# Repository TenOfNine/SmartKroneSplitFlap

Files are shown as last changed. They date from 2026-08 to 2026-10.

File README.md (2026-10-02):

<p align="center">Logo: KRONE REW als Fallblatt-Modulreihe</p>

# KRONE REW Fallblattanzeige — Ersatzsteuerung



Eigenbau-Steuerung für eine mechanische Fallblattanzeige der KRONE AG aus dem Jahr 1990. Die Original-Elektronik (Anzeigersteuerung und Palettensteuerungen PST mit HMCS44C) wird ersetzt. Mechanik und Anzeigenplatinen bleiben unverändert.

## Aufbau

```
ESP32-C3 (Master, WLAN/REST/MQTT)
  └─ RS-485 half duplex + CHAIN
       ├─ Daughter Card 1 (ATtiny1616) ── Anzeigenmodul 1
       ├─ Daughter Card 2 ────────────── Anzeigenmodul 2
       └─ …                                        bis 10
```

Jedes Anzeigenmodul erhält eine eigene kleine Steuerplatine, die die Hall-Impulse zählt, den Triac ansteuert und die aktuelle Blattposition kennt. Die Adressvergabe erfolgt automatisch entlang einer CHAIN-Leitung, sodass die Adresse der physischen Position entspricht und ein Kartentausch keine Einstellung erfordert.

## Eckdaten

| Größe | Wert |
|---|---|
| Anzeigenmodule | 10, Palettenmodulreihe A, Modulgröße 1 |
| Blätter je Modul | 40 |
| Zeichensatz | Leerbild, 0–9, A–Z, `-`, `.` |
| Zeit je Blatt | 60 ms, volle Umdrehung 2,40 s |
| Motor | Berger RSM 42/12, 42 V~, 250 U/min |
| Triac | Teccor L201E3, sensitives Gate |
| Modul-CPU | ATtiny1616 |
| Bus | RS-485, 115200 Bd, TP8485E |
| Master | ESP32-C3 Super Mini auf Trägerboard |

## Verzeichnisse

| Pfad | Inhalt |
|---|---|
| `docs/` | Spezifikation, Schaltpläne, Backlog, Toolchain, Symbolprüfungen, Prüfpunkte, Messprotokolle |
| `hardware/daughtercard/` | KiCad-Projekt der Modulsteuerung (geroutet, Fertigungspaket) |
| `hardware/master/` | KiCad-Projekt der Zentralsteuerung (geroutet, Fertigungspaket) |
| `firmware/module/` | ATtiny1616, PlatformIO |
| `firmware/master/` | ESP32-C3, PlatformIO (inkl. Web-UI, `prebuilt/` Flash-Image) |
| `tools/` | Setup, Schaltplan-/PCB-Generatoren, Router-Anbindung, Bus-Testwerkzeug |
| `reference/` | **Nicht versioniert.** Ablage für die Original-Herstellerunterlagen. |

## Stand

| Bereich | Stand |
|---|---|
| Spezifikation, Schaltplan (Netzliste) | vollständig, `docs/` |
| Schaltplan `.kicad_sch` + Footprints + PCB-Netzliste | generiert, ERC 0/0 (Daughter Card + Master) |
| PCB-Layout `.kicad_pcb` | geroutet, DRC 0 Fehler; Daughter Card bei JLCPCB bestellt, Master als Planungsstand |
| Modul-Firmware (ATtiny1616) | fertig, `firmware/module/` |
| Master-Firmware (ESP32-C3 Super Mini) | fertig, `firmware/master/` — Web-Flasher siehe unten |
| Bus-Werkzeug | `tools/busctl.py` |
| CI | `.github/workflows/ci.yml` |
| Offene Messungen O-2, O-5, O-6 | parametrisiert, blockieren die Fertigung nicht |

Der Projektstand für den Einstieg in eine neue Arbeitssitzung steht in
`docs/projektstand.md`.

## Einstieg

```bash
bash tools/setup.sh                              # Toolchain, siehe docs/toolchain.md
source .venv/bin/activate

pio test -e native -d firmware/module            # 62 Tests
pio test -e native -d firmware/master            # 40 Tests
python tools/test_busctl.py                      # 13 Tests
python tools/gen_daughtercard_sch.py --erc --pdf --png
```

## Firmware flashen

**Master (ESP32-C3 Super Mini).** Am einfachsten über den Browser-Flasher:
**<https://tenofnine.github.io/SmartKroneSplitFlap/>**

Nötig: Chrome oder Edge auf dem Desktop, ein USB-C-Kabel **mit Datenadern** an
die Buchse des Moduls. „Modul verbinden & flashen" drücken — der C3 geht selbst
in den Download-Modus, kein BOOT-Taster. Nach dem Flashen öffnet die Karte den
Access-Point `krone_anzeige` für die WLAN-Zugangsdaten. Das fertige Image liegt
committet unter `firmware/master/prebuilt/`; neu bauen mit
`python tools/build_master_firmware.py` oder direkt
`pio run -e esp32c3 -t upload -d firmware/master`.

Die Web-Oberfläche vorab ansehen — dieselbe Seite mit Beispieldaten und
simuliertem Bus, ohne Gerät:
**<https://tenofnine.github.io/SmartKroneSplitFlap/demo/>**
(erzeugt aus `firmware/master/src/main.cpp` per `python tools/build_webui_demo.py`).

Spätere Updates laufen über die Web-UI (*Einstellungen › Firmware aktualisieren*):
den **signierten Container** `firmware/master/prebuilt/krone-master-esp32c3.kota`
hochladen. Das Modul verlangt eine gültige ECDSA-Signatur des Projektschlüssels —
Einrichtung siehe [`docs/firmware-signing.md`](docs/firmware-signing.md). Der
Zugriff auf Web-UI/REST ist ab Werk auf private Netze beschränkt und lässt sich
mit einem Passwort schützen (*Einstellungen › Zugriffsschutz*).

**Daughter Card (ATtiny1616).** Über die UPDI-Stiftleiste J6 mit einem
USB-Seriell-Adapter (FTDI/CP2102/CH340, **auf 5 V**) und einem 4,7-kΩ-Widerstand
zwischen TXD und RXD:

```
  USB-Seriell-Adapter                       Daughter Card J6 (1×3)
  ┌───────────────┐
  │           GND ●──────────────────────────────● 1  GND
  │           TXD ●────[ 4,7 kΩ ]───┬────────────● 2  UPDI   (→ ATtiny PA0)
  │           RXD ●─────────────────┘
  │        5V/VCC ●──────────────────────────────● 3  +5V
  └───────────────┘        └─ nur wenn die Karte sonst keine 5 V hat
```

An UPDI kein Kondensator (Schaltplan 4.4). Dann:

- **Browser:** <https://tenofnine.github.io/SmartKroneSplitFlap/>,
  Tab *Daughter Card* — Werksflash (Bootloader + App + `BOOTEND`-Fuse).
  **Am Gerät verifiziert** (10.09.2026): Chip-Erase, Geräte-ID-Prüfung, Fuse-
  und Seitenschreiben sowie die Bootloader→App-Übergabe laufen auf echter
  Hardware durch.
- **Sicher:** `pio run -e attiny1616 -t upload -d firmware/module` (Protokoll
  `serialupdi`, Port ggf. per `--upload-port`).

Das committete Image liegt unter `firmware/module/prebuilt/`; neu bauen mit
`python tools/build_module_firmware.py`.

## Ausblick

**Modul-Firmware über den Bus verteilen** — die Master-Steuerung flasht die
Daughter Cards aus ihrer Web-UI, ohne PC und Adapter.

- **Residenter Bootloader (umgesetzt, experimentell).** `firmware/bootloader/`
  liegt im per Fuse `BOOTEND = 0x0C` abgetrennten Boot-Bereich (App ab 0x0C00,
  env `attiny1616_boot`). Bei jedem Reset läuft er zuerst, startet die App oder
  empfängt eine neue über den Bus (`ENTER_BOOTLOADER` → `FW_BEGIN`/`_DATA`/`_END`).
  Einzeln adressierbar, ausfallsicher (abgebrochene Updates sind wiederholbar,
  der Bootloader bleibt intakt). Der Master trägt die signierte Modul-Firmware
  eingebettet und verteilt sie aus *Einstellungen › Modul-Firmware*
  („Alle aktualisieren"). Erstflash von Bootloader + App + Fuse über den
  Browser-Werksflasher (Tab „Daughter Card") oder UPDI — **das Werksflashen
  selbst und die Bootloader→App-Übergabe sind am Gerät verifiziert**
  (10.09.2026). `BOOTEND` sperrt den Baustein nicht. Die **Verteilung über den
  Bus** (Master erkennt/aktualisiert die Modul-Firmware) ist noch nicht
  getestet — Design und Bench-Test-Checkliste in
  [`docs/module-bootloader.md`](docs/module-bootloader.md); bis dahin
  `pio run -e attiny1616 -t upload` (ohne Bootloader) als abgesicherter Weg – ab Firmware 1.16 (setzt bei `BOOTEND≠0` selbst IVSEL); ältere Plain-Apps auf einer werksgeflashten Karte (BOOTEND=0x0C) legen die Interrupts lahm – Issue #19.
- **UPDI-Ader im Flachbandkabel (verworfener Bastelweg).** Ader 9 des Busbands
  ist frei; eine Drahtbrücke je Karte von `J6.2` auf `J2.9` brächte UPDI auf den
  Bus, aber allen zehn Karten gemeinsam (kein Einzeladressieren). Der
  Bootloader-Weg ist die bessere Lösung.

## Hinweis zu den Originalunterlagen

Die technische Dokumentation der KRONE AG ist urheberrechtlich geschützt und trägt einen ausdrücklichen Vervielfältigungsvorbehalt. Sie gehört nach `reference/` und ist über `.gitignore` von der Versionierung ausgenommen. In den Dokumenten dieses Repositories wird auf Zeichnungsnummern verwiesen, nicht aus den Unterlagen zitiert.

Alle eigenen Inhalte — Spezifikation, Schaltplan, Firmware, Messprotokolle, Fotos der eigenen Hardware — sind davon nicht betroffen.

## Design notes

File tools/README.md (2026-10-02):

# tools

Python-Skripte laufen in der venv (`source .venv/bin/activate`) — **außer** die
mit `pcbnew`, die brauchen das System-Python (`/usr/bin/python3`).

## Einrichtung

| Werkzeug | Zweck |
|---|---|
| `setup.sh` | Toolchain der Entwicklungs-VM (KiCad 9, venv, PlatformIO, Bibliothekstabellen). `--kicad-config` nur die KiCad-Config. Siehe `docs/toolchain.md`. |
| `setup_freerouting.sh` | FreeRouting 2.3.0 + Temurin-JRE 25 nach `tools/vendor/` laden (gitignored). |

## Daughter Card (KiCad)

| Werkzeug | Zweck |
|---|---|
| `build_krone_symbols.py` | Symbolbibliothek `hardware/daughtercard/symbols/krone.kicad_sym`. `--check` für die CI. |
| `gen_daughtercard_sch.py` | Schaltplan + PDF + PNG + PCB-Netzliste aus `docs/schaltplan-daughtercard.md` Kap. 6. `--check-only`, `--erc`, `--pdf`, `--png`, `--netlist`. |
| `gen_daughtercard_pcb.py` | Erstplatzierung der `.kicad_pcb` (**System-Python**, `pcbnew`). `--png`, `--drc`, `--jlc`, `--render` (3D → `docs/render-daughtercard-*.png`, baut nicht neu). Verweigert Neuaufbau nach dem Routing nicht — dann UUID-Remapping statt Neu-Erzeugen. |
| `route_daughtercard.py` | FreeRouting + `finish_routes.py` + Masseflächen (**System-Python**). `--dry-run`, `--no-zones`. |
| `finish_routes.py` | A*-Rastersuch-Router für die 1–2 Verbindungen, die FreeRouting offen lässt. Von `route_*` importiert, braucht `python3-numpy`. |
| `add_silk_marks.py` | Maker-Kennzeichnung + schwarz/weiß-Lagenaufbau (**System-Python**). `--board <pfad>` auch für den Master. |
| `gen_manufacturing.py` | Fertigungspaket → `hardware/daughtercard/manufacturing/` (committet). `--no-gerber`. |

## Master / Zentralsteuerung (KiCad)

| Werkzeug | Zweck |
|---|---|
| `build_krone_master_symbols.py` | `hardware/master/symbols/krone_master.kicad_sym` (inkl. handgebautem `ESP32-C3-SuperMini`-Symbol). `--check` für die CI. |
| `gen_master_sch.py` | Schaltplan aus `docs/schaltplan-master.md` Kap. 6. Flags wie beim Daughter-Card-Pendant. |
| `gen_master_pcb.py` | Erstplatzierung `hardware/master/master.kicad_pcb` (**System-Python**). `PLACEMENT`-Dict (opt. 4. Element `"B"` = Rückseite). `--png`, `--drc`, `--jlc`, `--render` (3D aus der Datei), `--preview` (2D `docs/pcb-master.png` aus der Datei), `--force`. |
| `route_master.py` | wie `route_daughtercard.py` für die Master-Platine, ruft `add_silk_marks.py` selbst auf. FreeRouting mit `-Dfreerouting.gui.enabled=false` + Popen-Watchdog (JVM hängt sonst nach dem Routing), `--passes`-Default 6, bis zu 3 Anläufe. |
| `patch_master_pcb.py` | **inkrementell**: setzt die in `gen_master_pcb.PLACEMENT` neuen Refs in die geroutete Platine (`git show <base>`) ein, kappt kurzschließende Bahnen, schließt Lücken mit `finish_routes.py` (bis 4 Runden), setzt Referenztexte aus `REF_POS_MM`, baut Masseflächen neu, End-DRC. Für kleine Revisionen ohne Vollneuroute (Rev. 0.2: Q1/R8/D2). **System-Python.** |
| `gen_master_manufacturing.py` | Fertigungspaket → `hardware/master/manufacturing/`. |

## Firmware

| Werkzeug | Zweck |
|---|---|
| `check_flash.py` | Flash-Verbrauch einer ELF gegen eine Obergrenze prüfen (CI, ATtiny < 8 KB). |
| `check_webui.mjs` | prüft `INDEX_HTML` in `firmware/master/src/main.cpp`: JS-Syntax jedes Inline-`<script>` + optionaler jsdom-Smoke (Seite laden, `/api/*` mocken, Navigation testen). Prüft zusätzlich das Demo-Bundle, falls gebaut. `node tools/check_webui.mjs` (jsdom optional: `npm i jsdom@24`). |
| `build_webui_demo.py` | statische Demo der Master-Web-UI für die GitHub Page: schneidet `INDEX_HTML` aus `main.cpp`, setzt den Demo-Shim (`webui_demo_shim.html`, `window.fetch`-Überlagerung für `/api/*` mit Beispieldaten) davor → `firmware/master/prebuilt/demo/index.html` (gitignored, in CI/Pages erzeugt). `--check` = nur prüfen. |
| `build_master_firmware.py` | `pio run -e esp32c3` + `esptool merge_bin` → `firmware/master/prebuilt/` (`factory.bin` für USB + signierte `.kota` fürs Browser-OTA + Manifest). |
| `make_release.py` | Release-Paket: prüft Versionsgleichstand (Master, Modul, `module_fw.h`), CHANGELOG-Zeile und committete Prebuilts, legt das Tag `vMAJOR.MINOR` an. Der Tag-Push erzeugt per CI das GitHub-Release; Pages spiegelt es für die Versionsauswahl im Webflasher. |
| `build_module_firmware.py` | baut `attiny1616` (App @ 0x0000), `attiny1616_boot` (App @ 0x0C00) und den Bootloader → `firmware/module/prebuilt/` (drei Hex + signierte `.mota` für die Bus-Verteilung). |
| `ota_keys.py` | OTA-Signaturschlüssel: `init` (ECDSA-P-256-Paar + `lib/otaverify/ota_pubkey.h`), `pubkey`, `sign IN.bin OUT.kota`, `verify`. Privater Schlüssel nie im Repo. Siehe `docs/firmware-signing.md`. |

## Bus

| Werkzeug | Zweck |
|---|---|
| `busctl.py` | Kommandozeilenwerkzeug für den KRONE-REW-Bus (T9). |
| `test_busctl.py` | stdlib-`unittest` für `busctl.py` (13 Tests). |

## busctl.py

Für die stufenweise Inbetriebnahme nach `docs/spezifikation.md` Kapitel 10.
Enthält seit T17 auch die Bootloader-Kommandos (5.7, `GET_VERSION`/
`ENTER_BOOTLOADER`/`FW_BEGIN`/`FW_DATA`/`FW_END`, 0x54–0x58) — damit lassen
sich die Bench-Punkte 3+4 aus `docs/module-bootloader.md` (und mit `fwbegin`/
`fwdata`/`fwend` von Hand auch 5–8) direkt am PC gegen echte Karten prüfen,
ganz ohne Master-Hardware.

```bash
source ../.venv/bin/activate

# gegen echte Hardware (USB-RS485-Adapter):
python busctl.py --port /dev/ttyUSB0 enum
python busctl.py --port /dev/ttyUSB0 status 3
python busctl.py --port /dev/ttyUSB0 show 13 3 40 1 1     # SET_ALL + GO
python busctl.py --port /dev/ttyUSB0 sniff 10             # Rohrahmen mitschneiden
python busctl.py --port /dev/ttyUSB0 version 3             # GET_VERSION (App + Bootloader)
python busctl.py --port /dev/ttyUSB0 enterboot 3           # ENTER_BOOTLOADER

# Adapter ohne automatische Sende-/Empfangsumschaltung (z. B. ein MAX485-
# Modul mit getrennten DE/RE-Pins): DE und RE brücken, an RTS ODER DTR des
# USB-Serial-Adapters anschließen (je nachdem, was dort herausgeführt ist),
# dann --rts-rs485 bzw. --dtr-rs485:
python busctl.py --port /dev/ttyUSB0 --rts-rs485 enum
python busctl.py --port /dev/ttyUSB0 --dtr-rs485 enum

# ohne Hardware:
python busctl.py selftest              # Rahmen-/CRC-Logik
python busctl.py --sim 3 enum          # 3 simulierte Module
python busctl.py --sim 3 -v status 2   # -v zeigt die Rohrahmen
python test_busctl.py                  # Tests
```

Unterkommandos: `enum`, `status`, `uid`, `ping`, `set`, `show`, `home`, `stop`,
`config`, `sniff`, `selftest`.

Die Rahmen-/CRC-Logik ist ein eigenständiger Python-Nachbau von
`firmware/module/lib/protocol`. `selftest` prüft sie gegen dieselben Goldwerte
wie die C-Tests (CRC von `"123456789"` = `0x4B37`, Rahmenkopf `AA 55 05 01 03 28`).

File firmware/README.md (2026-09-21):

# firmware/

Master- und Modul-Firmware der KRONE-REW-Ersatzsteuerung. Details je Ziel:
[`master/README.md`](master/README.md) (ESP32-C3), [`module/README.md`](module/README.md)
(ATtiny1616). Gemeinsame Versionsnummer + Historie: [`CHANGELOG.md`](CHANGELOG.md).

## Speicherprofil

Firmware-Speicherprofil

Aufschlüsselung des Flash-Speicherverbrauchs nach Bereich (Web-UI/eigener Code,
WLAN-Stack, Krypto/TLS, Motor-/Enumerations-Logik, ...), gemessen am jeweils
gelinkten Firmware-Abbild (`firmware.map` bzw. `avr-nm --size-sort` gegen die
ELF-Datei). Die Modul-Zahlen stammen aus einem einmaligen Analyse-Build ohne
`-flto` (damit Funktionsgrenzen als eigene Symbole sichtbar bleiben) -- das
ausgelieferte Abbild wird weiterhin mit `-flto` gebaut und ist ein paar Bytes
kleiner.

Neu erzeugen nach jeder Firmware-Änderung:

```bash
python tools/gen_firmware_memory_chart.py
```

(Siehe CLAUDE.md Arbeitsweise -- gehört zu den nach jeder Firmware-Änderung neu
zu erzeugenden Dateien, wie `prebuilt/`.)

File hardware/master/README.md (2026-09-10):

# hardware/master

KiCad-Projekt der Zentralsteuerung (RS-485-Master, eine je Anlage).
**Stand:** Rev. 0.2 **fertig** — geroutet + GUI-Feinlayout (2 Lagen, ERC 0/0,
DRC 0/0/0), Symbolprüfung freigegeben, Fertigungspaket committet unter
`manufacturing/`. **Bereit zur Bestellung.** Rev. 0.2 = Eingangsschutz
(Verpol-P-FET Q1 + R8, RS-485-TVS D2) + Silk (+/- an J1, „ANT"-Text raus,
Referenztexte U2/D2/R4 am Bauteil). Die `master.kicad_pcb` ist der finale
Stand des Betreibers — nicht mehr per Skript regenerieren.

## Schnellcheck

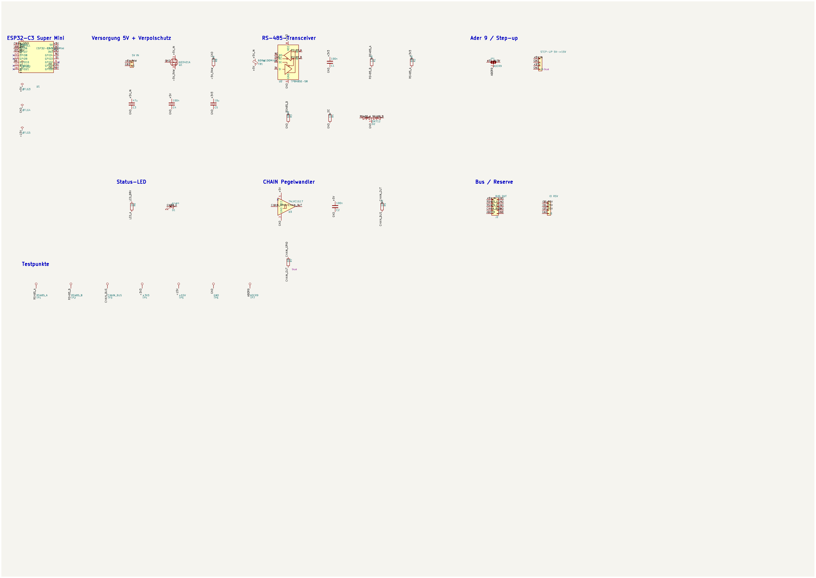
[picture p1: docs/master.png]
Schaltplan-Vorschau


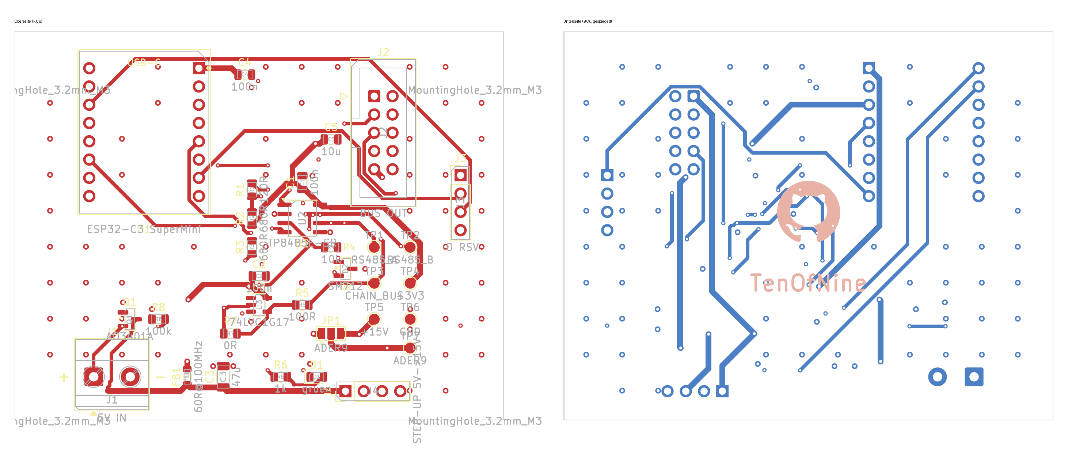
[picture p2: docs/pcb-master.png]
PCB (geroutet, F.Cu + B.Cu)


3D-Vorschau (`tools/gen_master_pcb.py --render`):

| Oberseite | Unterseite |
|---|---|
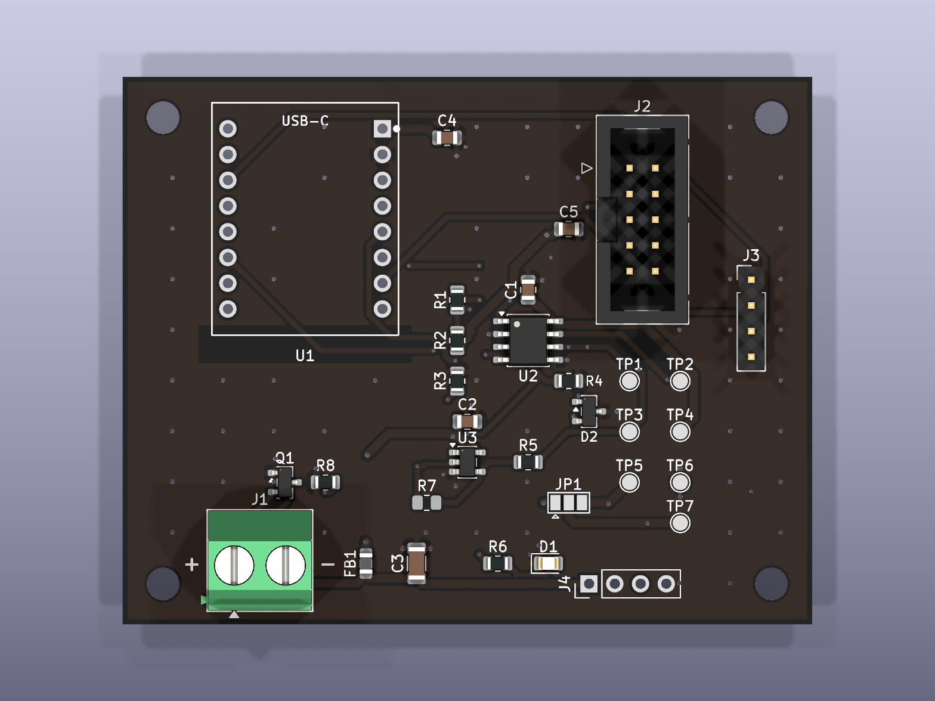
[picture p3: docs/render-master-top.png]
3D oben
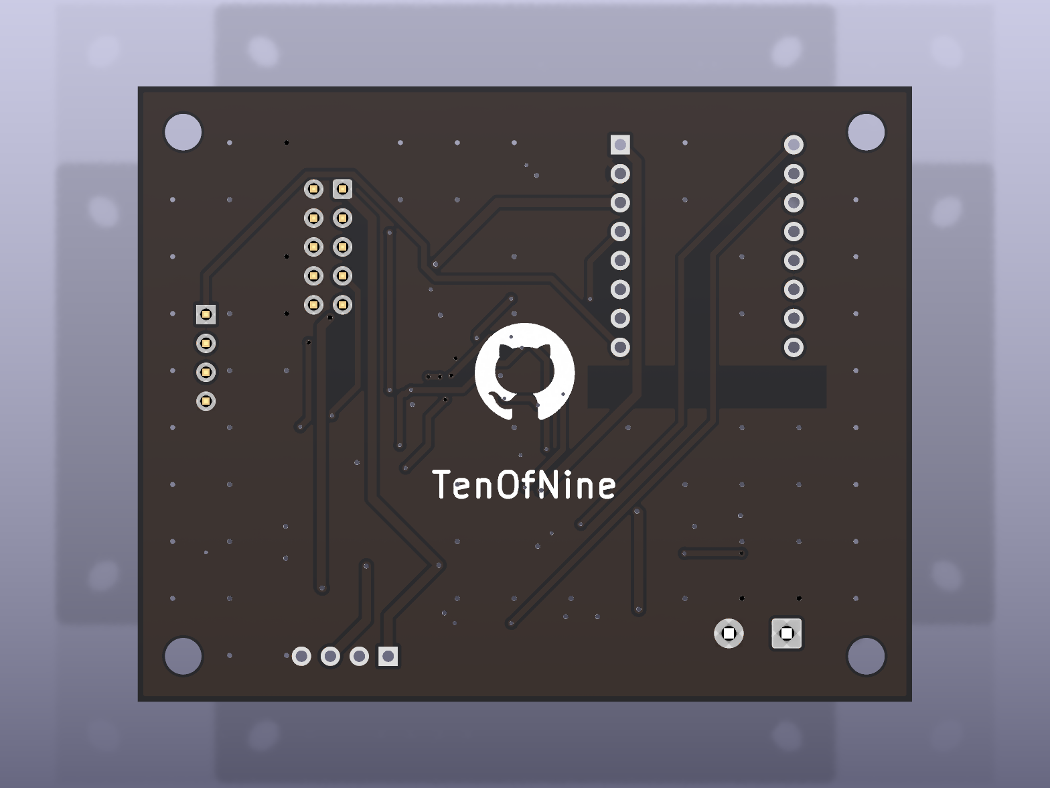
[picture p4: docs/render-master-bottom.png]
3D unten
|  |  |

Vollauflösung Schaltplan: [`docs/master.pdf`](../../docs/master.pdf) ·
ERC: 0 Fehler / 0 Warnungen (`gen_master_sch.py --erc`, in der CI geprüft) ·
DRC: 0 Fehler / 0 Warnungen / 0 unverdrahtet (Rev. 0.2). Feinlayout im GUI
(Bahnführung, Bestückungsdruck) ist Sache des Betreibers.

## Dateien

| Datei | Herkunft |
|---|---|
| `symbols/krone_master.kicad_sym` | **generiert** von `tools/build_krone_master_symbols.py`. Die 13 im Schaltplan verwendeten Symbole: Standardteile abgeflacht aus der KiCad-9-Bibliothek, `TP8485E-SR` wie bei der Daughter Card zusammengesetzt, `ESP32-C3-SuperMini` (16-Pin-Modul, 2×8) von Hand. Nicht bearbeiten. |
| `sym-lib-table` | projektlokale Bibliothekstabelle, bindet `krone_master` über `${KIPRJMOD}` ein |
| `footprints/logos.pretty/` | GitHub-Marke für die Rückseiten-Silkscreen (projektlokal, wie bei der Daughter Card) |
| `footprints/modules.pretty/` | `ESP32-C3-SuperMini.kicad_mod` — 2×8-THT für Buchsenleisten, Reihenabstand 15,24 mm, Pad 1 = 5V rechts oben, Antennen-Keepout an der Unterkante. Von Hand erstellt (kein Standard-Footprint). |
| `fp-lib-table` | projektlokale Footprint-Tabelle für die beiden `.pretty`-Ordner |
| `master.kicad_sch` | **generiert** von `tools/gen_master_sch.py` aus Netzliste (`docs/schaltplan-master.md` Kap. 6) und Footprint-Tabelle. 32 Bauteile, 20 Netze. |
| `master.kicad_pro` | Projektfile: projektlokale `sym-lib-table` / `fp-lib-table` + Netzklassen (Default, Power, GND — **kein AC**) aus Schaltplan Kap. 8 |
| `master.kicad_pcb` | Rev. 0.1: **Erstplatzierung** `tools/gen_master_pcb.py` + FreeRouting (`route_master.py`). Rev. 0.2 (Q1/R8/D2): **inkrementell** mit `tools/patch_master_pcb.py` in die geroutete Rev-0.1-Platine eingesetzt und mit `finish_routes.py` geschlossen (FreeRouting 2.3.0 hängt hier reproduzierbar). Maker-Mark / schwarz-weiß-Lagenaufbau von `tools/add_silk_marks.py --board …`. DRC 0/0. |
| `manufacturing/` | committetes Fertigungspaket (Gerber, Bohrdatei, Zip, BOM, CPL, README) von `tools/gen_master_manufacturing.py`. |
| `master.net` | **generiert** (`--netlist`), nicht versioniert. PCB-Netzliste. |

## Neu erzeugen

```bash
source .venv/bin/activate
python tools/build_krone_master_symbols.py                          # nur bei Änderung der Symbolauswahl
xvfb-run -a python tools/gen_master_sch.py --erc --pdf --png --netlist
```

**Vorsicht bei der `.kicad_pcb`:** Die Generatoren vergeben bei jedem Lauf neue
UUIDs. Solange die Platine noch nicht platziert/geroutet ist, gilt: `.kicad_sch`
+ `.kicad_pcb` nach einer Netzlistenänderung gemeinsam neu erzeugen und committen.
**Sobald die `.kicad_pcb` geroutet ist** (aktueller Stand), wird sie **nicht**
neu erzeugt — `tools/gen_master_pcb.py` verweigert den Neubau, wenn Bahnen oder
Zonen vorhanden sind (`--force`-Schutz). Eine Netzlistenänderung erfordert
stattdessen ein UUID-Remapping der Footprint-Pfade und danach
`tools/route_master.py`. Details: `docs/layout-master.md`.

| Flag (`gen_master_sch.py`) | Ausgabe |
|---|---|
| `--erc` | `docs/erc-master.rpt` |
| `--pdf` | `docs/master.pdf` |
| `--png` | `docs/master.png` (Vorschau ohne Rahmen, für GitHub) |
| `--netlist` | `master.net` (PCB-Netzliste, nicht versioniert) |

`--check-only` (bzw. `--check` bei `build_krone_master_symbols.py`) prüft ohne zu
schreiben — für die CI (T10). Der Check umfasst: jeder Pin an genau einem Netz
oder NC, jedes Bauteil mit vorhandenem Footprint.

Netznamen tragen im Netlist-Export das KiCad-übliche Wurzelblatt-Präfix (`/+5V`,
`/GND` …), weil die Rails über lokale Labels laufen. Für den PCB-Import ist das
unerheblich.

## Zum Schaltplan

Die Verbindungen werden über **gleichnamige lokale Labels an den Pins** hergestellt,
nicht über gezeichnete Leitungen. Die Bauteile liegen in einem groben Raster, nicht
handverlegt. Das ist bewusst so:

- Die menschenlesbare Darstellung der Schaltung ist `docs/schaltplan-master.md`
  Kapitel 5 (Prinzipschaltbilder) und Kapitel 6 (verbindliche Netzliste).
- Die `.kicad_sch` ist das maschinell erzeugte Abbild von Kapitel 6 für ERC,
  Netzlistenexport und das Layout.

## Layout und Routing

Footprints sind allen 32 Bauteilen zugeordnet (`FOOTPRINTS` in
`tools/gen_master_sch.py`). Die Platine ist geroutet — Erstplatzierung, Zonen,
Netzklassen (alle Bahnen 0,5 mm, Power `+5V(_RAW/_IN)`/`+3V3`/`+15V`/`ADER9`
0,8 mm mit 0,8-mm-Vias), Masseflächen F.Cu + B.Cu mit 5-mm-Stitching und die
offenen Punkte mit Layoutbezug stehen in
[`docs/layout-master.md`](../../docs/layout-master.md).
Die Massefläche ist nur im Antennenbereich unter U1 ausgespart (Footprint-Keepout).
Die JLCPCB-Bestückung beschreibt [`manufacturing/README.md`](manufacturing/README.md):
18 SMD-Teile (0805 / SOIC-8 / SOT-23 / SOT-23-5), alle LCSC-Basic; J1–J4,
U1-Sockel und JP1 von Hand.

## Prüfpunkte

`docs/symbolpruefung-master.md` ist vom Betreiber **freigegeben** (01.09.2026):
74LVC1G17 gegen Nexperia Rev. 16.1 §6.1, ESP32-C3-Modul-Pinbelegung und
Einbaulage aus den Betreiberfotos, TP8485E per Verweis. **Rev. 0.2 nachgetragen,
Freigabe offen:** AO3401A (SOT-23 1=G/2=S/3=D) und SM712 (Pin 3 = GND, gegen
Bourns-CDSOT23-SM712-Datenblatt).

Offen (blockieren die Fertigung nicht bzw. sind vor der Bestellung zu klären):

| Nr | Punkt | Wirkung |
|---|---|---|
| M-2 | Aufwärtswandler-IC + Pinbelegung | Boost-Steckplatz J4 bleibt DNP, bis O-2 gemessen ist |
| M-3 | CHAIN 3,3 V → 5 V | **entschieden:** U3 wird bestückt, R7 (0 Ω) DNP-Reserveplatz |
| M-4 | RS-485-TVS D2 (SM712/PSM712) | Pinbelegung gegen Bourns-Datenblatt geprüft; ProTek-Spot-Check + Freigabe vor Bestellung |
| O-2 | 5 V oder 12–20 V an Anzeige-Pin 9 | ob JP1 auf +15 V steht und der Boost bestückt wird |

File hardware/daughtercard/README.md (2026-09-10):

# hardware/daughtercard

KiCad-Projekt der Modulsteuerung (eine je Anzeigenmodul).
**Stand:** geroutet (2 Lagen, DRC 0 Fehler), Fertigungspaket committet unter
`manufacturing/`, bei JLCPCB in Auftrag.

## Schnellcheck

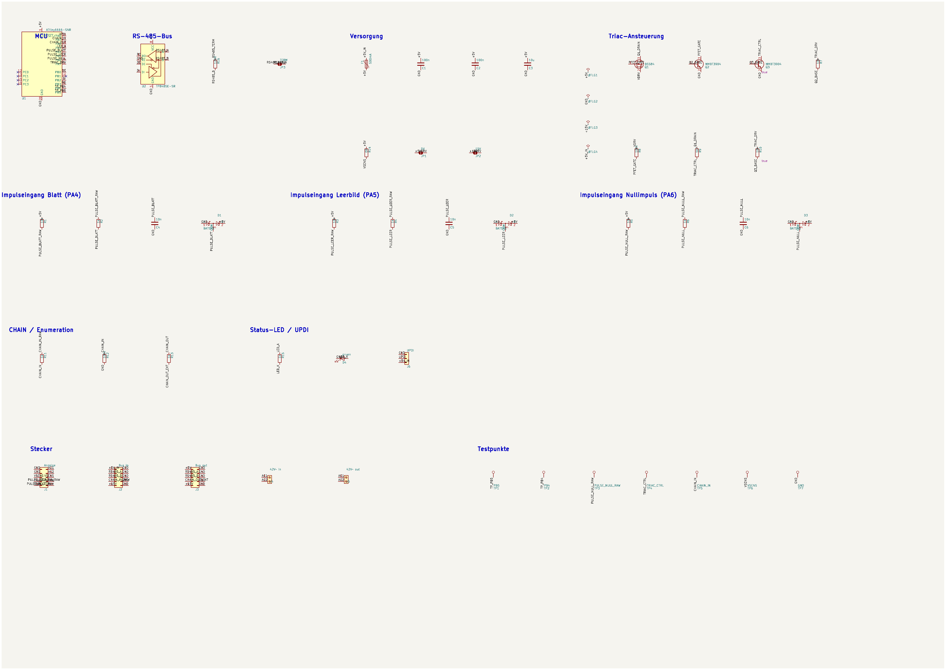
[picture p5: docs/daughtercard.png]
Schaltplan-Vorschau


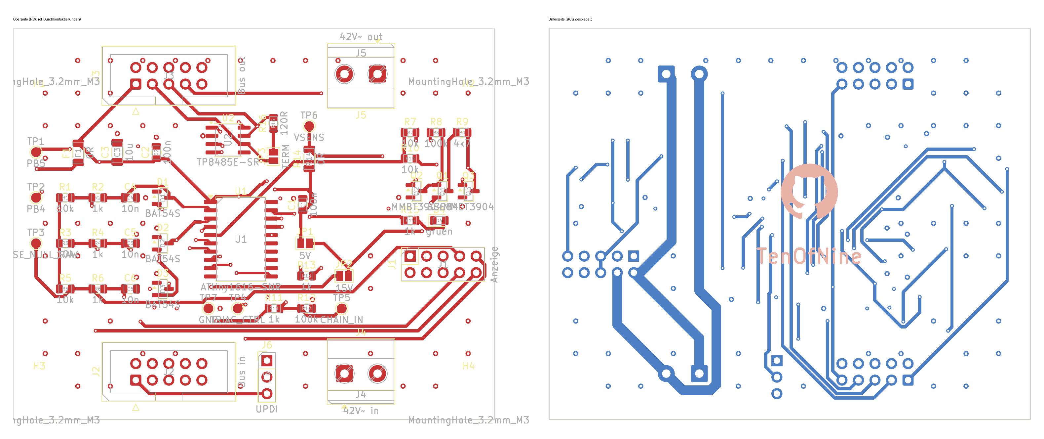
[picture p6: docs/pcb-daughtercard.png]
PCB (geroutet, F.Cu + B.Cu)


3D-Vorschau (`tools/gen_daughtercard_pcb.py --render`):

| Oberseite | Unterseite |
|---|---|
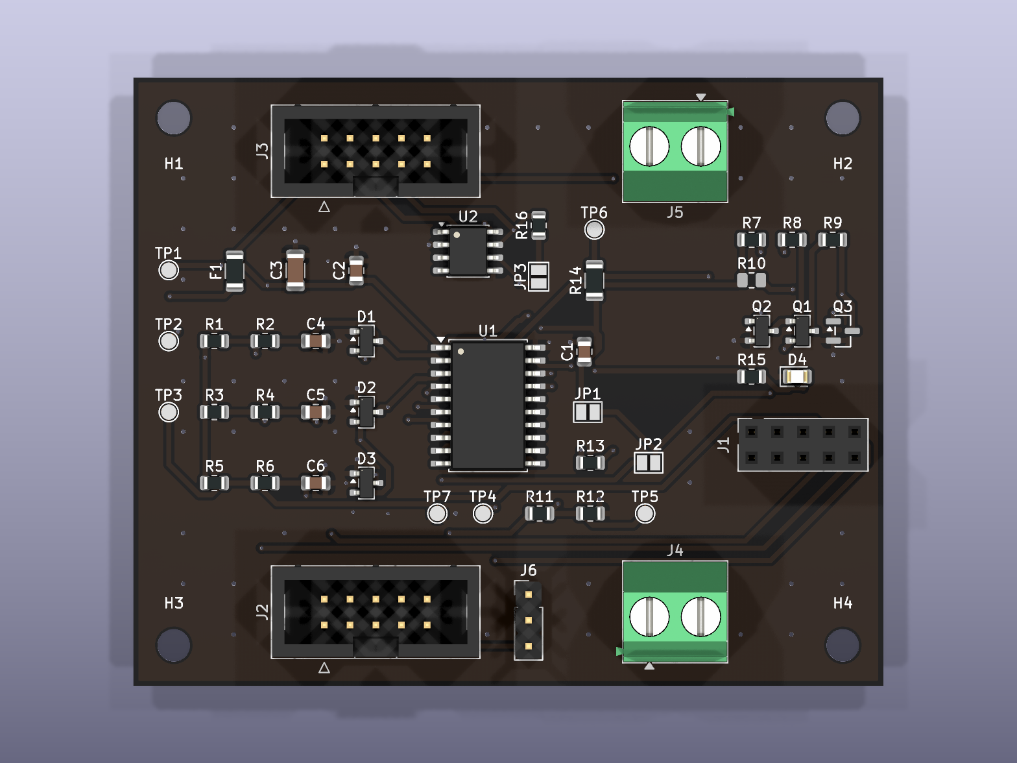
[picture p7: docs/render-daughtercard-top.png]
3D oben
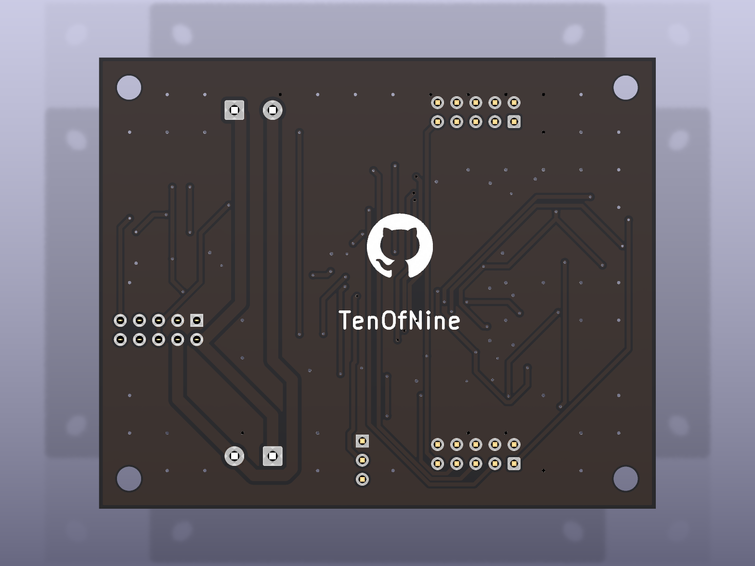
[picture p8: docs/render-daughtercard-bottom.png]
3D unten
|  |  |

Vollauflösung Schaltplan: [`docs/daughtercard.pdf`](../../docs/daughtercard.pdf) ·
ERC: 0 Fehler / 0 Warnungen (`gen_daughtercard_sch.py --erc`, in der CI geprüft)

## Dateien

| Datei | Herkunft |
|---|---|
| `symbols/krone.kicad_sym` | **generiert** von `tools/build_krone_symbols.py` aus der KiCad-9-Bibliothek. Alle 15 im Schaltplan verwendeten Symbole, abgeflacht. Nicht von Hand bearbeiten. |
| `sym-lib-table` | projektlokale Bibliothekstabelle, bindet `krone` über `${KIPRJMOD}` ein |
| `daughtercard.kicad_sch` | **generiert** von `tools/gen_daughtercard_sch.py` aus Netzliste (`docs/schaltplan-daughtercard.md` Kap. 6) und Footprint-Tabelle (T5) |
| `daughtercard.kicad_pro` | Projektfile: projektlokale `sym-lib-table` + Netzklassen (AC, RS485, Power) aus Schaltplan Kap. 8.2 |
| `daughtercard.kicad_pcb` | **Erstplatzierung** von `tools/gen_daughtercard_pcb.py` (System-Python, `pcbnew`), danach vom Betreiber feinjustiert und mit `tools/route_daughtercard.py` (FreeRouting + `finish_routes.py` + Masseflächen) verdrahtet. Maker-Mark / schwarz-weiß-Lagenaufbau von `tools/add_silk_marks.py`. |
| `manufacturing/` | committetes Fertigungspaket (Gerber, Bohrdatei, Zip, BOM, CPL, README) von `tools/gen_manufacturing.py`. |
| `daughtercard.net` | **generiert** (`--netlist`), nicht versioniert. PCB-Netzliste. |

## Neu erzeugen

```bash
source .venv/bin/activate
python tools/build_krone_symbols.py                            # nur bei Änderung der Symbolauswahl
python tools/gen_daughtercard_sch.py --erc --pdf --png --netlist
```

**Vorsicht bei der `.kicad_pcb`:** Die Generatoren vergeben bei jedem Lauf neue
UUIDs. Solange die Platine noch nicht platziert/geroutet ist, gilt: `.kicad_sch`
+ `.kicad_pcb` nach einer Netzlistenänderung gemeinsam neu erzeugen und committen.
**Sobald die `.kicad_pcb` platziert/geroutet ist** (aktueller Stand), wird sie
**nicht** neu erzeugt — eine Netzlistenänderung erfordert stattdessen ein
UUID-Remapping der Footprint-Pfade (siehe Commit „F1 → 0-Ω-Brücke") und danach
`tools/route_daughtercard.py`. Details: `docs/layout-daughtercard.md`.

| Flag | Ausgabe |
|---|---|
| `--erc` | `docs/erc-daughtercard.rpt` |
| `--pdf` | `docs/daughtercard.pdf` |
| `--png` | `docs/daughtercard.png` (Vorschau ohne Rahmen, für GitHub) |
| `--netlist` | `daughtercard.net` (PCB-Netzliste, nicht versioniert) |

`--check-only` (bzw. `--check` bei `build_krone_symbols.py`) prüft ohne zu schreiben —
für die CI (T10). Der Check umfasst: jeder Pin an genau einem Netz oder NC, jedes
Bauteil mit vorhandenem Footprint.

Netznamen tragen im Netlist-Export das KiCad-übliche Wurzelblatt-Präfix (`/+5V`,
`/GND` …), weil die Rails über lokale Labels laufen. Für den PCB-Import ist das
unerheblich; wer es ohne Präfix will, stellt die Rails auf Power-Symbole um.

## Zum Schaltplan

Die Verbindungen werden über **gleichnamige lokale Labels an den Pins** hergestellt,
nicht über gezeichnete Leitungen. Die Bauteile liegen in einem groben Raster, nicht
handverlegt. Das ist bewusst so:

- Die menschenlesbare Darstellung der Schaltung ist `docs/schaltplan-daughtercard.md`
  Kapitel 5 (Prinzipschaltbilder) und Kapitel 6 (verbindliche Netzliste).
- Die `.kicad_sch` ist das maschinell erzeugte Abbild von Kapitel 6 für ERC,
  Netzlistenexport und – nach dem Footprint-Schritt T5 – das Layout.

Eine handverlegte, ablesbare Schaltplanseite kann später folgen; sie ist nicht
Teil von T4.

## Layout (T5) und Routing

Footprints sind allen 48 Bauteilen zugeordnet (`FOOTPRINTS` in
`tools/gen_daughtercard_sch.py`). Die Platine ist geroutet — Zonen, Netzklassen
(alle Bahnen 0,5 mm außer AC 1,5 mm), Masseflächen und die offenen Punkte mit
Layoutbezug stehen in [`docs/layout-daughtercard.md`](../../docs/layout-daughtercard.md),
die JLCPCB-Bestückung in [`docs/jlc-bestueckung.md`](../../docs/jlc-bestueckung.md).

## Prüfpunkte

Die zwei Netzlisten-Entscheidungen aus T4 (P-1 Testpads, P-2 BAT54S) sind vom
Betreiber freigegeben, siehe [`docs/pruefpunkte-t4.md`](../../docs/pruefpunkte-t4.md).

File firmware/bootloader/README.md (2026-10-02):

# firmware/bootloader

Residenter Bootloader der Modulsteuerung (ATtiny1616, bare metal).
Am Gerät verifiziert seit Firmware v1.9 (Werksflash, Bus-Update Ende-zu-Ende,
siehe [`docs/module-bootloader.md`](../../docs/module-bootloader.md)).
Änderungen ab `BL_VERSION` 2 (`src/board.h`) sind bisher nur auf dem Host
getestet; der Bootloader erreicht die Karten nur per UPDI-Werksflash.

```bash
pio run -e bootloader        # ~2,7 KiB, Boot-Sektion 3 KiB (Fuse BOOTEND = 0x0C)
```

Liegt im Flash ab 0x0000, die Anwendung ab 0x0C00 (`firmware/module` env
`attiny1616_boot`). Empfängt die Firmware über USART0/RS-485 mit derselben
Rahmenschicht wie die App (`lib/protocol`), sammelt die Seiten über
`lib/fwupdate` und schreibt sie per `NVMCTRL`.

Alle Entscheidungen (Startfenster, App-Gültigkeit, Annahme von Rahmen,
Wiederaufsetzen) trifft `lib/fwupdate/fwboot` — hardwareunabhängig und mit
`pio test -e native -d firmware/module` (Suite `test_fwupdate`) getestet.
`src/main.c` macht nur Hardware: USART0 gepollt, TCB0 als 1-ms-Zeitbasis,
NVMCTRL, EEPROM. Hardwarenahe Konstanten stehen ausschließlich in
`src/board.h`.

Verhalten (BL_VERSION 2):

- App startbar = erstes App-Wort ≠ `0xFFFF` **und** EEPROM-Byte 8 = `0xA5`
  (Bus-Update fertig) oder `0xFF` (Werksflash).
- Startbare App, kein `ENTER_BOOTLOADER`-Marker → Startfenster 2,5 s (echte
  Zeit über TCB0). `FW_BEGIN` an die eigene Adresse startet ein Update, jeder
  andere Rahmen an sie startet sofort die App, Broadcasts und fremde Adressen
  verlängern oder beenden das Fenster nicht.
- Sonst warten. Nach `FW_BEGIN` (Byte 8 = `0x00`) ist die App bis zum
  erfolgreichen `FW_END` nicht startbar — weder nach Busstille noch nach einem
  Neustart.
- Wiederaufsetzbar: Wiederholung des letzten `FW_DATA` wird bestätigt,
  `FW_BEGIN` startet jederzeit neu, Leerlauf beendet die Übertragung nicht.
- Nur Unicast an die eigene Adresse (ungültige EEPROM-Adresse → 250) mit
  passender Nutzlastlänge; Antwort frühestens 200 µs nach Rahmenende.
- `GET_VERSION`: `[1 · 0xFF · 0xFF · flags · BL_VERSION]`, `APP_VALID` nach
  aktuellem Stand.

Der Bootloader konfiguriert den Triac-Treiberpin (PA7) nie als Ausgang (setzt
nur dessen Ausgangslatch auf low) → der Motor kann hier nicht bestromt werden;
eigener Watchdog als Hänge-Schutz.

Erstflash + Fuse weiterhin über UPDI/J6 (Werksflasher `updi.js` oder
`pio -t upload` + `pymcuprog`).

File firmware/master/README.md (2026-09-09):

# firmware/master

Zentralsteuerung der Fallblattanzeige (**ESP32-C3 Super Mini**, PlatformIO,
Arduino-ESP32). Zielhardware: `hardware/master`, Pinbelegung
`docs/schaltplan-master.md` Kap. 6.

## Aufbau

| Teil | Inhalt | Bezug |
|---|---|---|
| `lib/charmap/` | Text → Fallblatt-Positionen, Umlaute, Ausrichtung, Kürzung | Spez. 7.4, Anhang A |
| `lib/clocktext/` | Uhrzeit → `HH.MM` / `HH.MM.SS` | Spez. 7.6 / 7.7 |
| `lib/busmaster/` | Master-Protokollseite: Frames, Enumeration, Modul-Statustabelle, Timeout/Retry | Spez. 4.5, 5 |
| `lib/masterapp/` | Betriebsarten, Anzeige-Update bei Änderung, Auto-Rückfall der Sekundenanzeige, Status-JSON | Spez. 7.3, 7.5, 7.7 |
| `lib/hadiscovery/` | Home-Assistant-MQTT-Auto-Discovery (Config-Topic + Payload je Entity) | Spez. 7.6 |
| `lib/eventlog/` | Ereignis-Ringpuffer (32 Einträge) für den Log-Tab der Web-UI | — |
| `lib/moduleupdate/` | Sende-Seite der Firmware-Verteilung über den Bus (Warteschlange + Zustandsautomat, host-getestet) | Spez. 5.7 |
| `src/main.cpp` | ESP32-C3-Glue: UART1-RS485 (Halbduplex), WiFiManager, WebServer/REST, PubSubClient/MQTT, NTP, OTA, mDNS, Status-LED, Web-UI |

`lib/protocol/` wird über `lib_extra_dirs = ../module/lib` mit der Modul-Firmware
geteilt. Die `lib/`-Bausteine sind hardwareunabhängig und auf dem Host getestet.

## Tests (Host)

```bash
source ../../.venv/bin/activate
pio test -e native
```

`test_charmap`, `test_clocktext`, `test_busmaster`, `test_masterapp`,
`test_hadiscovery`, `test_eventlog`, `test_otaverify`, `test_moduleupdate` (57 Fälle). `test_masterapp` und
`test_busmaster` treiben die Logik gegen einen **simulierten Bus** (aufgezeichnete
Sende-Frames, eingespeiste Antworten) — das deckt „REST-Endpunkte antworten gegen
einen simulierten Bus" aus Backlog T8 ab.

## Firmware bauen und aufspielen

```bash
pio run  -e esp32c3                     # ~1 MB Flash
pio run  -e esp32c3 -t upload           # USB-C
python tools/ota_keys.py init           # einmalig: OTA-Signaturschluessel
python tools/build_master_firmware.py   # -> prebuilt/ (factory.bin + signierte .kota)
```

**Erst-Flash (USB):** Browser-Flasher **<https://tenofnine.github.io/SmartKroneSplitFlap/>**
(`prebuilt/index.html`, per GitHub Actions veröffentlicht — lädt immer den zuletzt
committeten Stand), esptool-js oder `esptool.py`. Datei: `prebuilt/krone-master-esp32c3.factory.bin`.

**Spätere Updates (OTA):** In der Web-UI unter *Einstellungen › Firmware
aktualisieren* den **signierten Container** `prebuilt/krone-master-esp32c3.kota`
hochladen (nicht die `.factory.bin`). Das Modul prüft ECDSA-P-256-Signatur und
SHA-256, schreibt dann in die zweite App-Partition und startet neu; fremde oder
beschädigte Dateien werden abgelehnt, die laufende Firmware bleibt aktiv. Kein
Toolchain, jeder Browser. In den *Schnittstellen* abschaltbar; ein Netzwerk-OTA
à la ArduinoOTA/espota gibt es bewusst nicht (offener Port ohne Passwort).
Schlüsselverwaltung: `docs/firmware-signing.md`.

Pin-/UART-Belegung steht in `platformio.ini` (`build_flags`), damit `main.cpp`
portabel bleibt; die Vorgaben in `main.cpp` sind dieselben Werte. RS-485 auf
**UART1** (der C3 hat nur UART0 = USB-Konsole und UART1). CHAIN läuft über den
nicht invertierenden Pegelwandler 74LVC1G17 (3,3 V → 5 V), bleibt also high-aktiv.
Die Status-LED (GPIO6, D1): Dauerlicht = alles gut, langsames Blinken = ein Modul
offline/Fehler, schnelles Blinken = kein WLAN.

Beim Erststart öffnet die Karte einen Access-Point (`krone_anzeige`) mit Captive
Portal für die WLAN-Zugangsdaten. MQTT-Broker danach unter `/api/config` bzw. in
der Web-UI.

Die **Modulzahl wird per Enumeration automatisch erkannt** (`cfg.module_count = 0`);
solange keine Karte antwortet, scannt der Master alle ~10 s neu. *Einstellungen ›
Anzeige* erlaubt bei Bedarf eine feste Feldbreite (`1…32`) als Override.

## Web-UI

Eine vom ESP32-C3 ausgelieferte Seite (System-Schriften, kein CDN, ~14 KB),
Dark-Theme, Ansichten **Übersicht** (Split-Flap-Statusstreifen, Kacheln,
Schnellaktionen), **Module** (Tabelle), **Log**, **Einstellungen** (WLAN wechseln,
feste IP, NTP-Server + Zeitzone als Städteliste mit Sommerzeit-Schalter + Uhr
manuell, MQTT, Anzeige, Schnittstellen-Schalter, Zugriffsschutz, System,
Firmware aktualisieren). Der Quelltext ist `INDEX_HTML` in `src/main.cpp`.

## REST

| Methode | Pfad | Body / Zweck |
|---|---|---|
| GET | `/api/status` | Anzeige + Module (Ist/Ziel/Zustand/Fehler/Korr./Blattzahl/FW/verpasst) |
| GET | `/api/system` | Uptime, Heap (frei/gesamt/min), **CPU-Last, Chiptemperatur**, Sketch/OTA-Platz, Hostname, WLAN, Uhr, MQTT/OTA/mDNS, Bus-CRC/Timeouts, `detected`/`field_width`/`auto_modules`, FW-Build |
| GET | `/api/log` | `?sev=info\|warn\|err` — Ereignis-Ringpuffer |
| GET/POST | `/api/backup` | Vollsicherung **inkl. WLAN-Zugangsdaten** (Download / Restore). POST übernimmt und startet neu. |
| POST | `/api/update` | Signiertes OTA: Container `.kota` als multipart (Feld `firmware`) → Signatur-/Hash-Prüfung → `Update`-Bibliothek → Neustart |
| POST | `/api/log/clear` | Log leeren |
| POST | `/api/text` | `{"text":"HALLO"}` |
| POST | `/api/mode` | `{"mode":"clock_hm","sep":".","align":1}` |
| POST | `/api/home` | `{}` oder `{"addr":3}` |
| POST | `/api/selftest` | `{}` |
| POST | `/api/module` | `{"addr":3,"action":"home\|stop\|identify"}` |
| POST | `/api/enumerate` | Enumeration neu starten |
| POST | `/api/time` | `{"iso":"2026-09-01T14:07:00"}` — Uhr manuell stellen |
| GET | `/api/wifi/scan` | erreichbare Netze |
| POST | `/api/wifi` | `{"ssid":"…","psk":"…"}` — Netz wechseln (Rückfall nach ~25 s) |
| POST | `/api/wifi/portal` | Konfigurationsportal öffnen |
| POST | `/api/reboot` | Neustart |
| GET/POST | `/api/config` | Hostname, MQTT, NTP-Server, TZ, feste IP, Ausrichtung, Trennzeichen, Modulzahl, hh:mm:ss-Timeout, `net_scope`, `admin_user`/`admin_pass` (nur schreibend), Schalter MQTT/REST-Schreib-API/OTA/mDNS |
| GET | `/api/module/firmware` | gebündelte Modul-Version + je Modul installierte Version/Status (experimentell, Spez. 5.7) |
| POST | `/api/module/update` | `{"all":true}` oder `{"addr":[2,3]}` — Firmware über den Bus verteilen |
| GET | `/api/module/update/status` | Fortschritt/Ergebnis der laufenden Verteilung |

Die schreibenden Steuer-Endpunkte lassen sich über den Schalter
**REST-Schreib-API** sperren (`403`). Die Web-Oberfläche selbst nicht.

## Zugriffsschutz

Ein Wrapper prüft vor **jedem** Endpunkt (`web_begin()` → `guard()`):

- **Herkunft** — `cfg.net_scope`: `0` alle · `1` private Netze (RFC 1918) +
  eigenes Subnetz *(Vorgabe)* · `2` nur eigenes Subnetz. Sonst `403`. Weil ein
  Router-Port-Forward die echte öffentliche Absender-IP durchreicht, greift ein
  Internetzugriff bei `1`/`2` nicht. SoftAP-Portal + `127.0.0.1` immer erlaubt.
- **Anmeldung** — ist `cfg.admin_pass` gesetzt: HTTP-Basic-Auth auf allen
  Endpunkten (`401` sonst), Benutzer `cfg.admin_user`. Leer = keine Anmeldung.

Beides unter *Einstellungen › Zugriffsschutz*. `admin_pass` wird nie ausgeliefert
(`/api/config` GET zeigt nur `admin_set`), steht aber in der `/api/backup`-Sicherung.

## MQTT / Home Assistant

Broker, Port, Benutzer/Passwort und Basis-Topic (Default `krone/anzeige`) unter
*Einstellungen › MQTT*. Beim Verbinden sendet die Karte die
Auto-Discovery-Configs unter `homeassistant/…` (retained) — in HA erscheint ein
Gerät „KRONE Fallblattanzeige" mit Text, Betriebsart, Homing/Selbsttest,
Sammelfehler und je Modul Zeichen + Online-Status.

- **Verfügbarkeit:** `<base>/status` = `online`/`offline` (Last Will, retained);
  jede Entity trägt es als `availability_topic` und wird bei Ausfall „nicht
  verfügbar".
- **Zustände** werden retained gesendet (`text/state`, `mode/state`,
  `module/<n>/char` = dargestelltes Zeichen, `module/<n>/online`, `error/state`),
  Aktualisierung ~1×/s.
- Broker-Reconnect alle 5 s (im Log sichtbar). Client-ID = Hostname → bei mehreren
  Mastern eindeutig halten.
- Kein TLS — nur im vertrauenswürdigen Netz betreiben.
- Broker-ACL (falls gesetzt): pub+sub auf `krone/anzeige/#`, pub auf
  `homeassistant/#`.

Details und die Topic-Tabelle: `docs/spezifikation.md` 7.6.

## Persistenz

Alle Einstellungen (inkl. WLAN-, MQTT- und Admin-Zugangsdaten) liegen im NVS und
**überstehen OTA-Updates**. Nur ein USB-Flash mit „Erase" löscht sie — dann in
den Einstellungen unter *System* die zuvor gesicherte `krone-backup.json` wieder
einspielen. Deshalb setzt das Flasher-Manifest `new_install_prompt_erase: false`.

## Abweichungen von Spezifikation 7.2

Eingebauter `WebServer` statt `ESPAsyncWebServer`, `Preferences` (NVS) statt
`LittleFS` — dependency-arm und mit arduino-esp32 3.x ohne Patches lauffähig.
Begründung in `docs/toolchain.md` Abschnitt 4. **Kein `ArduinoOTA`** — Updates
laufen über `POST /api/update` (Browser) bzw. USB; das spart einen offenen,
passwortlosen OTA-Port.

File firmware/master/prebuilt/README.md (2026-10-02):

# Vorgebaute Master-Firmware (ESP32-C3 Super Mini)

Erzeugt von `tools/build_master_firmware.py` aus `firmware/master/` (zuletzt gebaut nahe Commit `2e79c3e`, 2026-10-02). Bei jeder Firmware-Aenderung neu ausfuehren.

| Datei | Zweck |
|---|---|
| `index.html` | Web-Flasher (ESP Web Tools). Wird per GitHub Actions als Page veroeffentlicht. |
| `krone-master-esp32c3.factory.bin` | Merged-Image fuer den **Erst-Flash ueber USB** (Offset 0x0) |
| `krone-master-esp32c3.kota` | **signierter** App-Container fuer das **OTA-Update aus der Web-UI** (Einstellungen > Firmware aktualisieren). Header mit SHA-256 + ECDSA-P-256-Signatur; das Modul lehnt fremde/manipulierte Dateien ab. Siehe `docs/firmware-signing.md`. |
| `manifest.json` | Manifest fuer [ESP Web Tools](https://esphome.github.io/esp-web-tools/) |

SHA-256 `factory.bin`: `2479e861d54a37312dd09fbac3f0156a288f90c23a4ec0f1b2f7d03bece7cb6f`  
SHA-256 `kota`: `2866525f8106a5b856b9ae2c8d36b2d8a5e70afd982953bc654fc1fcdc0d2a6a`

## Erst-Flash (USB)

- **Browser:** <https://tenofnine.github.io/SmartKroneSplitFlap/> (laedt immer diesen Verzeichnisstand). Chrome/Edge Desktop.
- Alternativ [esptool-js](https://espressif.github.io/esptool-js/) — `factory.bin` an Offset `0x0`. Der C3 Super Mini geht ueber die USB-C-Buchse selbsttaetig in den Download-Modus (kein BOOT-Taster).
- Kommandozeile:

  ```
  esptool.py --chip esp32c3 -p /dev/ttyACM0 write_flash 0x0 krone-master-esp32c3.factory.bin
  ```

## Spaetere Updates (OTA)

*Einstellungen > Firmware aktualisieren* -> `krone-master-esp32c3.kota` hochladen (nicht die `.factory.bin`). Das Modul prueft Signatur und Pruefsumme, schreibt in die zweite App-Partition und startet neu; fremde oder beschaedigte Dateien werden abgelehnt, die laufende Firmware bleibt aktiv. Kein Toolchain, jeder Browser. In den *Schnittstellen* abschaltbar; ein Netzwerk-OTA (ArduinoOTA) gibt es bewusst nicht.

Nach dem Boot: Access-Point `krone_anzeige` fuer die WLAN-Einrichtung, serielle Konsole auf USB-C (115200 Bd). Status-LED (GPIO6): schnelles Blinken = kein WLAN.

> `index.html` ist handgepflegt und wird von diesem Skript **nicht** ueberschrieben.

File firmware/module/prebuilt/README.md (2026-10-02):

# Vorgebaute Modul-Firmware (ATtiny1616)

Erzeugt von `tools/build_module_firmware.py` (zuletzt nahe Commit `2e79c3e`, 2026-10-02). Bei jeder Firmware-Aenderung neu ausfuehren.

| Datei | Zweck |
|---|---|
| `krone-daughtercard-attiny1616.hex` | App @ 0x0000, **ohne** Bootloader. `pio run -e attiny1616 -t upload` bzw. `pymcuprog`. Der abgesicherte Weg ab Firmware 1.16 (setzt bei `BOOTEND != 0` selbst IVSEL; aeltere Plain-Apps legen auf werksgeflashten Karten die Interrupts lahm, Issue #19). |
| `krone-daughtercard-bootloader.hex` | residenter Bootloader @ 0x0000 (Werksflash). |
| `krone-daughtercard-attiny1616-boot.hex` | App @ 0x0C00, laeuft hinter dem Bootloader (Werksflash). |
| `krone-daughtercard-attiny1616.mota` | signierter Container der `-boot`-App fuer die Firmware-Verteilung ueber den Bus (der Master bettet sie ein). |

SHA-256 (`krone-daughtercard-attiny1616.hex`): `29d45dc5f29e7b6e8431b2a952426643c9e2fa7982d996132b24756a9b749b70`

## Flashen

- **Toolchain (sicher ab Firmware 1.16):** `pio run -e attiny1616 -t upload -d firmware/module`.
- **Browser-Werksflash (experimentell):** <https://tenofnine.github.io/SmartKroneSplitFlap/>, Tab *Daughter Card*. Schreibt Bootloader + `-boot`-App und setzt die Fuse `BOOTEND = 0x0C`. USB-Seriell-Adapter (5 V) mit 4,7-kOhm-Bruecke TX--RX an J6 (TX/RX -> Pin 2 UPDI, GND -> Pin 1, +5 V -> Pin 3).
- **Ueber den Bus:** ist ein Bootloader geflasht, aktualisiert der Master die Karten aus seiner Web-UI (*Einstellungen > Modul-Firmware*). Siehe `docs/module-bootloader.md`.

Der Flasher prueft die Geraete-ID (ATtiny1616 = `1E 94 21`). `krone-daughtercard-attiny1616.mota` vorhanden.

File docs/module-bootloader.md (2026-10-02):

# Modul-Bootloader und Firmware-Verteilung über den Bus

> **Status: experimentell.** Der **Werksflash über den Browser** (Bootloader +
> App + `BOOTEND`-Fuse, Bench-Punkte 1+2) ist **am Gerät verifiziert**
> (10.09.2026). Die **Firmware-Verteilung über den Bus** (Punkte 3–8):
> erster realer Test am Gerät (19.09.2026) deckte einen Bug im Bootloader
> auf (derselbe DI-Pin-Fehler wie in der App vor `f24b861`, eigene
> USART0-Initialisierung — behoben in `3d65464`, Firmware v1.9).
>
> **21.09.2026 — erste vollständige End-zu-Ende-Übertragung am Gerät
> bestätigt** (Adresse 1, `FW_BEGIN`→`FW_DATA`→`FW_END`→`GET_VERSION`
> ohne einen einzigen Retry, neue Version per `GET_VERSION` bestätigt).
> Dabei zeigte sich aber ein zweiter, eigenständiger Bug: eine Karte, die
> mitten in `FW_DATA`/`FW_END` hängen bleibt (App bereits ungültig
> markiert, Bootloader wartet laut Design korrekt auf ein neues
> `FW_BEGIN`), beantwortet `CMD_GET_STATUS` nicht mehr und gilt dem
> Master daher als „offline". **„Alle aktualisieren"/„Veraltete
> aktualisieren" filtern aber beide auf online** — eine so hängen
> gebliebene Karte konnte dadurch nie wieder erreicht werden, nur noch
> per Browser-Werksflash. Fix (firmware v1.14): neuer Button „Offline
> erneut versuchen" + `handle_module_update()` lässt explizit angefragte
> Adressen immer zu, unabhängig vom Online-Status (siehe
> `firmware/CHANGELOG.md`). `pio run -e attiny1616 -t upload` (App @
> 0x0000, ohne Bootloader) bleibt der abgesicherte Weg, wenn eine Karte
> dennoch per Browser-Werksflash zurückgeholt werden muss – **erst ab
> Firmware 1.16**: Der Upload schreibt keine Fuses, eine werksgeflashte
> Karte behält `BOOTEND = 0x0C`. Ältere Plain-Apps setzen dann IVSEL nicht,
> ihre Interrupts landen mitten im Code und die Zeitbasis steht (Issue #19);
> ab 1.16 setzt die Plain-App IVSEL selbst.
>
> **Stand 1.16 (Review-Fixes, Issues #29/#30/#41):** Der Bootloader (BL-
> Version 2) startet nach einem `FW_BEGIN` bis zum erfolgreichen `FW_END`
> in keinem Pfad die App – auch nicht nach Busstille. Die Wiederholung des
> zuletzt angenommenen Chunks wird quittiert, `FW_BEGIN` startet jederzeit
> neu, der Zeitablauf wird nur von eigenen Rahmen zurückgesetzt. Er nimmt
> nur Unicast an die eigene Adresse an (bei ungültiger EEPROM-Adresse 250),
> wartet 200 µs vor jeder Antwort, das Startfenster dauert echte 2,5 s
> (TCB0). Als „App startbar" gelten nur die Marker 0xA5 und 0xFF. Der Master
> wiederholt je Schritt bis zu dreimal, beginnt danach einmal neu und prüft
> ein verlorenes `FW_END`-ACK per `GET_VERSION`. **Bootloader-Änderungen
> erreichen Bestandskarten nur per Browser-Werksflash** – die vier Karten im
> Feld laufen bis dahin mit BL 1.

## Ziel

Die Master-Steuerung spielt den Daughter Cards die Firmware **über den vorhandenen
RS-485-Bus** ein — kein PC, kein UPDI-Adapter, einzeln adressierbar, ausfallsicher.

## Flash-Aufteilung (ATtiny1616, 16 KiB)

```
  0x0000 ┌─────────────────────┐
         │  Bootloader         │  Fuse BOOTEND = 0x0C  (0x0C * 256 = 0x0C00)
  0x0C00 ├─────────────────────┤
         │  Anwendung          │  gebaut mit env attiny1616_boot
         │  (Vektortabelle,    │  (-Wl,--section-start=.text=0x0C00, -DHAS_BOOTLOADER)
         │   IVSEL = 0)        │
  0x2400 ├─────────────────────┤
         │  frei               │
  0x4000 └─────────────────────┘
```

- Der Bootloader belegt ~2,5 KiB, die Boot-Sektion 3 KiB. Die App belegt ~5,6 KiB.
- **`BOOTEND` sperrt den Baustein nicht.** UPDI hat weiter vollen Zugriff und kann
  den Fuse jederzeit zurücksetzen. `LOCKBIT` wird nicht gesetzt; wäre es gesetzt,
  entsperrt ein UPDI-Chip-Erase wieder. Die einzige echte Aussperr-Falle wäre
  `SYSCFG0.RSTPINCFG` weg von UPDI — das ändert weder der Bootloader noch der
  Werksflash.
- Interruptvektoren: tinyAVR-1 hat `CPUINT.CTRLA.IVSEL`. Nach Reset = 0 (Vektoren
  in der App-Sektion). Der Bootloader nutzt **keine Interrupts**; er setzt vor dem
  Sprung `CPUINT.CTRLA = 0`, die App setzt es zusätzlich selbst (`#ifdef HAS_BOOTLOADER`).

## Ablauf

**Reset → Bootloader.** Prüft `GPIOR0` (Marker `0xB7`, von `CMD_ENTER_BOOTLOADER`)
und `app_valid()` (erstes App-Wort ≠ `0xFFFF` **und** EEPROM-Byte 8 ≠ `0x00`).

- gültige App, kein Marker → ~2,5 s auf `CMD_FW_BEGIN` lauschen, sonst App starten.
- Marker gesetzt **oder** keine gültige App → im Bootloader bleiben und warten.

**Update-Sitzung** (Master-getrieben, bestehende Rahmenschicht `lib/protocol`):

| Kommando | Payload | Antwort |
|---|---|---|
| `CMD_ENTER_BOOTLOADER` (0x55) | — | — (Modul: `GPIOR0=0xB7`, SW-Reset) |
| `CMD_FW_BEGIN` (0x56) | `len16 · crc16` (CRC16/MODBUS über das Image) | `[0x01]` ok / `[0x00]` nak |
| `CMD_FW_DATA` (0x57) | `off16 · bis 30 Byte` | `[0x01]` / `[0x00]` |
| `CMD_FW_END` (0x58) | — | `[0x01]` ok / `[Fehlercode]` |
| `CMD_GET_VERSION` (0x54) | — | `[1 · maj · min · flags · bl_ver]` |

Der Bootloader markiert die App bei `FW_BEGIN` als ungültig (EEPROM-Byte 8 = 0x00),
schreibt die Seiten per `NVMCTRL` (Erase+Write) ab 0x0C00, prüft bei `FW_END`
Länge und CRC, setzt dann Byte 8 = `0xA5` und startet per SW-Reset neu.

**Fehler / Stromausfall:** die App bleibt ungültig → beim nächsten Reset bleibt der
Bootloader im Update-Modus, der Master wiederholt. Der Bootloader selbst kann von
App-Code nicht überschrieben werden (Hardware-Schutz der Boot-Sektion).

## Motorsicherheit

Der Bootloader konfiguriert **PA7 (Triac-Treiber) nie als Ausgang** → der
Transistor bleibt gesperrt, der Motor kann im Bootloader nicht bestromt werden,
egal welcher Fehler auftritt. Der Bootloader hat einen eigenen Watchdog (~1 s).
Die App-seitige Laufzeitüberwachung (Fehlercode 0x05) und der App-Watchdog bleiben
unverändert. Der Bootloader löscht beim Start nur das Ausgangslatch von PA7
(`OUTCLR`), für den Fall, dass er ohne Reset erreicht wird.

## Bausteine

| Ort | Inhalt |
|---|---|
| `firmware/bootloader/` | der Bootloader (`pio run -e bootloader`) |
| `firmware/module` env `attiny1616_boot` | App @ 0x0C00, `CMD_GET_VERSION`/`CMD_ENTER_BOOTLOADER` |
| `firmware/module/lib/fwupdate/` | empfangsseitiger Seiten-Sammler (host-getestet) |
| `firmware/master/lib/moduleupdate/` | sendeseitige Warteschlange + Zustandsautomat (host-getestet) |
| `firmware/master/src/module_fw.h` | signierter `.mota`-Container der App, in die Master-Firmware eingebettet (Option A) |
| `tools/build_module_firmware.py` | baut alle drei Images + signiert die `.mota` |

Der Master prüft die eingebettete `.mota` beim Start gegen `ota_pubkey.h`
(dieselbe ECDSA-Kette wie das Master-OTA). Der Bootloader prüft nur die CRC —
Vertrauensanker ist der Master.

## Master-Web-UI

*Einstellungen › Modul-Firmware*: Tabelle mit installierter vs. gebündelter
Version je Adresse, Status (aktuell / Update verfügbar / kein Bootloader /
offline), Buttons **„Alle aktualisieren"** und **„Veraltete aktualisieren"**.
Läuft ein Update, ruht der Statusverkehr auf dem Bus; die Module werden
nacheinander abgearbeitet, das jeweils betroffene ist einige Sekunden eingefroren.

REST: `GET /api/module/firmware`, `POST /api/module/update` (`{"all":true}` oder
`{"addr":[2,3]}`), `GET /api/module/update/status`.

## Bench-Test-Checkliste (vor dem ersten Einsatz)

> **Verkabelung vorbereitet (11.09.2026):** zwei Daughter Cards vollständig
> bestückt (alle Anschlüsse gelötet) und per Flachbandkabel in Reihe
> verbunden, Durchgangsprüfung der Kette ok. Reine Verkabelungs-/
> Lötprüfung — noch kein Signal auf dem Bus. Deckt Punkte 3–7 vor, sobald
> die Master-Hardware aufgebaut ist.
>
> **`tools/busctl.py` beherrscht seit T17 auch die Bootloader-Kommandos**
> (`version`/`enterboot`/`fwbegin`/`fwdata`/`fwend`, 0x54–0x58) — Punkte 3+4
> und mit `fwbegin`/`fwdata`/`fwend` von Hand auch 5–8 lassen sich damit
> direkt über einen USB-Serial-Adapter (z. B. FTDI + separates RS-485-Modul
> mit `--rts-rs485`) testen, **ohne** dass die Master-Hardware aufgebaut sein
> muss. `POST /api/module/update` (Master-Web-UI) bleibt der bequeme Weg für
> den Praxisbetrieb mit mehreren Karten.

1. ✅ **Bootloader isoliert.** `pio run -e bootloader`, per UPDI @ 0x0000 flashen,
   Fuse `BOOTEND = 0x0C` setzen (`pymcuprog write -m fuses -o 8 --values 0x0C`
   oder der Werksflasher). Ohne App: bleibt der Bootloader im Warte-Loop, WDT
   löst nicht aus (kein Dauerreset).
   **Verifiziert 10.09.2026** über den Browser-Werksflasher (schreibt
   Bootloader + Fuse in einem Zug): Chip-Erase, Geräte-ID, Fuse- und
   Seitenschreiben liefen sauber, kein Dauerreset.
2. ✅ **Sprung in die App.** `attiny1616_boot`-App @ 0x0C00 dazuflashen. Reset →
   Bootloader übergibt an die App (Interruptvektoren korrekt, IVSEL = 0) —
   **verifiziert** (Status-LED blinkt/leuchtet wie von der App vorgegeben, der
   1-ms-Timer-Interrupt läuft also). RS-485-Kommunikation + Motorsteuerung im
   Zusammenspiel mit dem Master noch offen (Punkte 3+, Master-Hardware
   bestellt, noch nicht aufgebaut).
3. **`CMD_GET_VERSION`.** Master (oder `busctl.py version <addr>`) fragt Version
   ab, bekommt `1 · 1 · 0 · 0x03 · x` (App gültig + Bootloader vorhanden).
4. **`CMD_ENTER_BOOTLOADER`.** Master (oder `busctl.py enterboot <addr>`) schickt
   die Karte in den Bootloader; sie bleibt dort.
5. **Update über den Bus.** `POST /api/module/update` für eine Karte. Verlauf im
   Log; nach `FW_END` startet die Karte neu, `GET_VERSION` bestätigt die Version.
6. **Abbruch mitten im Transfer** (Karte kurz stromlos): App bleibt ungültig,
   Bootloader wartet, Master-Wiederholung bringt sie zurück.
7. **„Alle aktualisieren"** mit mehreren Karten: nacheinander, andere Module
   bleiben erreichbar.
8. **CRC-Fehlerpfad**: eine bewusst verfälschte `.mota` → Bootloader lehnt bei
   `FW_END` ab, App bleibt ungültig.
9. Bus-Signalintegrität + Dauer bei zehn Karten am realen Kabelbaum messen.

## Werksflash über den Browser

`firmware/master/prebuilt/updi.js`, Tab *Daughter Card*: Chip-Erase → Bootloader
+ `-boot`-App → `BOOTEND = 0x0C` → `BODCFG = 0xE5`. Geräte-ID-Prüfung (`1E 94 21`).
Der Fuse-Write folgt der `pymcuprog`-v0-Sequenz (ADDR + DATA + `WFU`), inklusive
Rücklese-Prüfung.

**BODCFG (21.09.2026):** Bisher nirgends konfiguriert (Werksvorgabe `0x00` =
Brown-out-Detection komplett aus) — Verdacht nach einem Fall, in dem eine Karte
nach längerer Stromlosigkeit ohne erkennbaren Grund softwareseitig nicht mehr
ansprechbar war. `0xE5` = `LVL=BODLEVEL7` (4,2 V, höchste verfügbare Stufe;
Datenblatt DS40002204A S. 2 nennt für 20 MHz 4,5–5,5 V, mehr als 4,2 V bietet
der Chip nicht) + `ACTIVE=ENABLED` + `SLEEP=ENABLED` (beide kontinuierlich,
Kapitel 17.5.1/17.5.2). Zusätzlich neue Diagnose-Log-Zeilen: `updi.js` liest
EEPROM-Byte 8 (Bootloader-Marker „App gültig") direkt nach dem Chip-Erase und
nochmal unmittelbar vor dem Neustart aus — damit sichtbar wird, falls ein
alter Marker aus einem abgebrochenen Bus-Update den Chip-Erase überlebt.

Der Seitenpuffer wird wie in SerialUPDI (megaTinyCore) mit **`CTRLA.RSD = 1`**
(Response Signature Disable) beschrieben: ohne RSD schickt das Modul nach jedem
ST-Byte ein ACK, das auf der Ein-Draht-Leitung mit den folgenden Datenbytes
kollidiert. Mit RSD gehen `REPEAT` + `ST` (Wort) + 64 Datenbytes +
`STCS(CTRLA, RSD=0)` in einem Transfer raus, danach nur das Echo lesen.

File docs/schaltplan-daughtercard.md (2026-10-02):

# Schaltplan Daughter Card — KRONE REW Fallblattanzeige

| Feld | Wert |
|---|---|
| Baugruppe | Modulsteuerung, eine je Anzeigenmodul |
| Version | 0.7 |
| Datum | 01.09.2026 |
| Bezug | Technische Spezifikation v0.8 (Steckerbelegung J1) |
| Status | Netzliste in `.kicad_sch` überführt (ERC 0/0), PCB geroutet (DRC 0), Fertigungspaket `hardware/daughtercard/manufacturing/`, bei JLCPCB in Auftrag. Freigegebene Korrekturen: P-1, P-2 (`docs/pruefpunkte-t4.md`), P-3 RS-485-Pins (`docs/pruefpunkte-t7.md`). |

**Zum Gebrauch:** Kapitel 3 bis 6 zusammen ergeben den vollständigen Schaltplan. Kapitel 5 zeigt die Blöcke als Prinzipschaltbild, Kapitel 6 ist die verbindliche Netzliste. Bei Abweichungen zwischen beiden gilt die Netzliste.

---

## 1. Konventionen

- Alle passiven SMD-Bauteile in Bauform 0805, sofern nicht anders angegeben. 0805 lässt sich noch gut von Hand nacharbeiten.
- Widerstände 1 %, Kondensatoren X7R, 50 V.
- Nicht bestückte Positionen sind mit **DNP** gekennzeichnet.
- Netznamen sind in Großbuchstaben gesetzt.

---

## 2. Blockschaltbild

```
   J4 42V~ in ──┬──────────────────────────────────┬── J5 42V~ out
                └────────────► J1.2 / J1.4 ◄───────┘

   J2 Bus in ──┬── +5V ──┬─────────────────────────┬── J3 Bus out
               │         ├── U1 ATtiny1616         │
               │         ├── U2 TP8485E            │
               │         └── R14 ── VSENS ── J1.5/6│
               │                                    │
               ├── A / B ──── U2 ───── U1 USART ────┤
               │                                    │
               └── CHAIN ──► U1 PA1      U1 PA2 ────┘ (CHAIN)

                            U1 PA4 ◄── Filter ◄── J1.10  Blattimpuls
                            U1 PA5 ◄── Filter ◄── J1.8   Leerbildimpuls
                            U1 PA6 ◄── Filter ◄── J1.7   Nullimpuls
                            U1 PA7 ──► Treiber ──► J1.9  Triac
                            U1 PA0 ◄──────────────  J6   UPDI
                            U1 PA3 ──► D4                Status-LED
```

---

## 3. Stückliste

### 3.1 Aktive Bauteile

| Ref | Bauteil | Gehäuse | Anmerkung |
|---|---|---|---|
| U1 | ATtiny1616-SNR | SOIC-20 (300 mil) | Verfügbarkeit bei JLCPCB prüfen, sonst nachbestücken |
| U2 | TP8485E-SR | SOIC-8 | LCSC C94206 |
| Q1 | BSS84 | SOT-23 | P-Kanal, High-Side im Quelle-Zweig |
| Q2 | MMBT3904 | SOT-23 | Pegelwandler für Q1 |
| Q3 | MMBT3904 | SOT-23 | **DNP**, Senke-Zweig, Alternative zu Q1/Q2 |
| D1–D3 | BAT54S | SOT-23 | Doppel-Schottky als Klemmdioden |
| D4 | LED grün | 0805 | Status |

### 3.2 Passive Bauteile

| Ref | Wert | Funktion |
|---|---|---|
| R1, R3, R5 | 10 kΩ | Pull-up der Impulseingänge nach +5V |
| R2, R4, R6 | 1 kΩ | Serienwiderstand der Impulseingänge |
| C4, C5, C6 | 10 nF | Tiefpass der Impulseingänge, τ = 10 µs |
| R7 | 10 kΩ | Basiswiderstand Q2 |
| R8 | 100 kΩ | Gate-Pull-up Q1 nach VDRV |
| R9 | 4,7 kΩ | R_S, Vorwiderstand Triac-Eingang. Bei 5-V-Betrieb auf 1,2 kΩ ändern, siehe O-2 |
| R10 | 10 kΩ | Basiswiderstand Q3, **DNP** |
| R11 | 1 kΩ | Serienwiderstand CHAIN_IN |
| R12 | 100 kΩ | Pull-down CHAIN_IN |
| R13 | 1 kΩ | Serienwiderstand CHAIN_OUT |
| R14 | 0 Ω | Brücke +5V nach VSENS, Bauform 1206 (Handlöt-Brücke) |
| R15 | 1 kΩ | Vorwiderstand D4 |
| R16 | 120 Ω | Busabschluss, über JP3 zuschaltbar. Bauform **0805** (P ≈ 50 mW; 120 Ω gibt es bei JLCPCB nur in 0805 als Basic Part) |
| C1 | 100 nF | Abblockung U1, direkt an Pin 1/20 |
| C2 | 100 nF | Abblockung U2, direkt an Pin 8/5 |
| C3 | 10 µF / 16 V | Stützkondensator +5V, Keramik oder Tantal |
| F1 | 0-Ω-Brücke, 1206 | +5V_IN → +5V. War als PTC 0,5 A vorgesehen; bei 10 Modulen in Reihe läge der Kettenstrom über dem Auslösewert, daher feste Brücke. Absicherung: Firmware-Watchdog + Laufzeitgrenze (Spez. 8) |

### 3.3 Mechanik

| Ref | Bauteil | Anmerkung |
|---|---|---|
| J1 | Buchsenleiste 2×5, 2,54 mm, gerade | board-to-board direkt auf den Pfostenstecker der Anzeigenplatine (Referenz BKL 10120960). Kein kodierter Wannenstecker — Verpolschutz siehe 4.1 |
| J2, J3 | Wannenstecker 2×5, 2,54 mm, gerade | Bus ein / Bus aus |
| J4, J5 | Schraubklemme 2-polig, 5,08 mm | 42 V~ ein / aus |
| J6 | Stiftleiste 1×3, 2,54 mm | UPDI |
| JP1, JP2 | Lötjumper 2 Pad | Auswahl VDRV |
| JP3 | Lötjumper 2 Pad | Busabschluss |
| TP1–TP7 | Testpads Ø 1,5 mm | siehe 6.4 |

---

## 4. Steckverbinder

### 4.1 J1 — zur Anzeigenplatine (KRONE 6281 3 160-00)

Bauform **Buchsenleiste 2×5, 2,54 mm, gerade** (Referenz BKL 10120960). Die
Daughter Card wird huckepack direkt auf den vorhandenen Pfostenstecker der
Anzeigenplatine gesteckt, kein Flachbandkabel. Pin 1 der Buchsenleiste liegt auf
Pin 1 der Anzeige.

| Pin | Netz | Richtung |
|---|---|---|
| 1 | GND | — |
| 2 | AC1 | zur Anzeige |
| 3 | GND | — |
| 4 | AC2 | zur Anzeige |
| 5 | VSENS | zur Anzeige |
| 6 | VSENS | zur Anzeige |
| 7 | PULSE_NULL_RAW | von der Anzeige |
| 8 | PULSE_LEER_RAW | von der Anzeige |
| 9 | TRIAC_CTRL | zur Anzeige |
| 10 | PULSE_BLATT_RAW | von der Anzeige |

> ⚠️ **Verpolschutz — J1 ist nicht kodiert.** Pin 2 und Pin 4 führen die 42 V~.
> Wird die Karte um 180° verdreht aufgesteckt, landet die 42 V~ auf
> TRIAC_CTRL/VSENS und den Impulseingängen und zerstört U1, U2 und Q1/Q2. Die
> Buchsenleiste passt in beiden Drehlagen auf den Pfostenstecker — es gibt keine
> mechanische Sperre wie beim früher vorgesehenen Wannenstecker.
>
> Abzusichern durch:
> 1. **Mechanik.** Die Kartenbefestigung (Abstandsbolzen, Gehäuse) so gestalten,
>    dass nur eine Drehlage passt. Die vier symmetrischen Eckbohrungen allein
>    genügen nicht. Siehe offener Punkt in `docs/pruefpunkte-j1-buchsenleiste.md`.
> 2. **Kennzeichnung.** Pin-1-Dreieck im Bestückungsdruck auf der Bauteilseite,
>    zusätzlich Text „PIN1 → ANZEIGE PIN1" neben J1.
> 3. **Durchgangsprüfung vor dem ersten Einschalten** (Prüfliste 9,
>    Inbetriebnahme 10): J1.2 und J1.4 gegen die 42-V~-Pins der Anzeige, nicht
>    gegen die Versorgung. Die Zählrichtung ist auf der Lötseite der Anzeige mit
>    2, 4, 6, 8, 10 in einer Reihe beschriftet.

### 4.2 J2 / J3 — Bus

Identische Belegung, alle Netze werden durchverbunden **außer CHAIN**.

| Pin | J2 (Bus in) | J3 (Bus out) |
|---|---|---|
| 1 | +5V | +5V |
| 2 | GND | GND |
| 3 | RS485_A | RS485_A |
| 4 | GND | GND |
| 5 | RS485_B | RS485_B |
| 6 | GND | GND |
| 7 | **CHAIN_IN** | **CHAIN_OUT** |
| 8 | GND | GND |
| 9 | +15V | +15V |
| 10 | GND | GND |

Pin 7 ist der einzige Pin, der **nicht** durchverbunden wird. Genau dadurch bricht die Kette an jeder Karte auf, was die positionsabhängige Enumeration erst möglich macht. J2 Pin 7 der ersten Karte geht an den CHAIN-Ausgang des Masters.

Ader 9 bleibt unbelegt, falls O-2 ergibt, dass 5 V zur Ansteuerung genügen.

### 4.3 J4 / J5 — Motorspannung

| Pin | Netz |
|---|---|
| 1 | AC1 |
| 2 | AC2 |

J4 und J5 sind direkt parallel geschaltet und dienen dem Durchschleifen von Karte zu Karte.

> ⚠️ AC1 und AC2 sind **potenzialfrei** gegenüber GND. Sie dürfen an keiner Stelle mit der Logikmasse verbunden werden.

### 4.4 J6 — UPDI

| Pin | Netz |
|---|---|
| 1 | GND |
| 2 | UPDI |
| 3 | +5V |

Der für SerialUPDI übliche Widerstand von 4,7 kΩ sitzt im Adapter, nicht auf der Karte. An UPDI darf kein Kondensator liegen.

---

## 5. Schaltungsblöcke

### 5.1 Versorgung

```
   J2.1 ──[F1 0 Ω]──┬── +5V ──┬── U1.1 (VDD)
                         │         ├── U2.8 (VCC)
                         │         ├── JP1 ── VDRV
                         │         └──[R14 0Ω]── VSENS ── J1.5, J1.6
                         │
                        [C3 10µ]
                         │
   J2.2, .4, .6, .8, .10 ┴── GND

   C1 100n direkt zwischen U1.1 und U1.20
   C2 100n direkt zwischen U2.8 und U2.5

   J2.9 ── +15V ── JP2 ── VDRV
```

VSENS ist über R14 fest mit +5V verbunden. Ergibt Teststufe 1, dass die Hall-Sensoren bei 5,0 V unzuverlässig arbeiten — die Originaldokumentation nennt +5 bis +6 V — lässt sich R14 auslöten und VSENS über TP6 aus einer separaten Quelle speisen.

**JP1 und JP2 dürfen niemals gleichzeitig geschlossen sein.** Genau einer der beiden wird gebrückt.

### 5.2 RS-485-Anbindung

```
   U1.8  (PB3, RXD)  ◄──────── U2.1 (RO)
   U1.11 (PB0, XDIR) ───────► U2.3 (DE)
   U1.9  (PB2, TXD)  ───────► U2.4 (DI)
                              U2.2 (/RE) ── GND
                              U2.5 (GND) ── GND
                              U2.8 (VCC) ── +5V

   U2.6 (A) ──┬── J2.3, J3.3
              │
            [JP3]
              │
           [R16 120Ω]
              │
   U2.7 (B) ──┴── J2.5, J3.5
```

Die drei USART0-Leitungen liegen auf der **Standard-MUX-Position** des ATtiny1616:
TXD = PB2, RXD = PB3, XDIR = PB0 (PB1 ist XCK und bleibt im Async-Betrieb frei).
Siehe `docs/pruefpunkte-t7.md` P-3.

/RE liegt fest auf Masse, der Empfänger ist also dauerhaft aktiv. Die Karte liest ihre eigene Sendung zurück; die Firmware verwirft dieses Echo im Normalbetrieb und nutzt es zur Kollisionserkennung.

JP3 wird **nur auf den beiden Karten an den physikalischen Enden des Busses** geschlossen. Die Fail-Safe-Vorspannung sitzt ausschließlich am Master.

### 5.3 Impulseingänge (dreimal identisch)

```
   +5V ──[R1 10k]──┬── J1.10 (PULSE_BLATT_RAW)
                   │
                   └──[R2 1k]──┬── U1.2 (PA4)
                               │
                        [C4 10n]  [D1 BAT54S]
                               │        │
                              GND   +5V / GND
```

| Signal | Anzeige-Pin | Pull-up | Serie | C | Diode | ATtiny |
|---|---|---|---|---|---|---|
| PULSE_BLATT | J1.10 | R1 | R2 | C4 | D1 | Pin 2, PA4 |
| PULSE_LEER | J1.8 | R3 | R4 | C5 | D2 | Pin 3, PA5 |
| PULSE_NULL | J1.7 | R5 | R6 | C6 | D3 | Pin 4, PA6 |

Ruhepegel high, der Hall-Sensor zieht im Impuls nach Masse. Auswertende Flanke ist die **fallende**. Der Senkenstrom beträgt 0,5 mA je Eingang.

D1–D3 sind BAT54S, ein Doppel-Schottky in Reihe. Pinbelegung nach dem KiCad-Symbol `Diode:BAT54S`: **Pin 1 = A, Pin 2 = K, Pin 3 = COM** (Mittelabgriff). Für den Rail-Clamp liegt Pin 1 (A) auf GND, Pin 2 (K) auf +5V, das gefilterte Signal am Mittelabgriff Pin 3. Eine Spitze über +5V fließt über die Diode COM→K ab, eine unter GND über die Diode A→COM. Diese Zuordnung wurde in T4 gegenüber der Erstfassung korrigiert, siehe `docs/pruefpunkte-t4.md` P-2.

PULSE_NULL wird von der Firmware nicht ausgewertet und dient allein als Messpunkt.

### 5.4 Triac-Ansteuerung

Zwei alternative Zweige. **Nur einer wird bestückt.**

**Quelle-Zweig (Vorgabe, bestückt)**

```
                    VDRV
                     │
                  [R8 100k]
                     │
   U1.5 ──[R7 10k]── │ ── Basis Q2 (MMBT3904)
   (PA7)             │        Emitter ── GND
                     │        Kollektor ──┐
                     ├────────────────────┘
                     │
                 Gate Q1 (BSS84)
                     │
   VDRV ── Source Q1 ── Drain Q1 ──[R9 4k7]── J1.9 (TRIAC_CTRL)
```

PA7 high schaltet Q2 durch, zieht das Gate von Q1 nach Masse und schaltet damit VDRV über R9 auf Pin 9 der Anzeige. R8 hält Q1 im Ruhezustand sicher gesperrt. Bei VDRV = 15 V liegt V_GS von Q1 bei −15 V und damit innerhalb der zulässigen ±20 V des BSS84.

Der Zweig funktioniert unverändert mit VDRV = 5 V oder 15 V; nur R9 ist anzupassen.

**Senke-Zweig (Alternative, DNP)**

```
   U1.5 ──[R10 10k]── Basis Q3 (MMBT3904)
   (PA7)                  Emitter ── GND
                          Kollektor ── J1.9 (TRIAC_CTRL)
```

Falls die Messung ergibt, dass Pin 9 der Anzeige nach Masse gezogen werden muss statt bestromt zu werden. Dann werden Q1, Q2, R7, R8, R9 nicht bestückt und stattdessen Q3 und R10 gesetzt.

In beiden Zweigen gilt: **PA7 high bedeutet Motor an.** Eine Invertierung in der Firmware gibt es nicht; das Flag-Bit 2 der EEPROM-Konfiguration ist reserviert und wird von der Firmware ab v1.16 immer gelöscht (Issue #18).

### 5.5 CHAIN

```
   J2.7 ──[R11 1k]──┬── U1.17 (PA1, CHAIN_IN)
                    │
              [R12 100k]
                    │
                   GND

   U1.18 (PA2, CHAIN_OUT) ──[R13 1k]── J3.7
```

R12 sorgt dafür, dass ein offener CHAIN-Eingang als inaktiv gelesen wird — wichtig für die erste Karte im Werkstattbetrieb und bei gezogenem Buskabel.

### 5.6 Status-LED und UPDI

```
   U1.19 (PA3) ──[R15 1k]──▶|── GND        (D4)

   U1.16 (PA0) ──────────────── J6.2       (UPDI)
```

### 5.7 Motorspannung

```
   J4.1 ──┬── AC1 ──┬── J1.2
          │         │
          └─────────┴── J5.1

   J4.2 ──┬── AC2 ──┬── J1.4
          │         │
          └─────────┴── J5.2
```

Reine Durchverbindung, kein aktives Bauteil im AC-Pfad.

---

## 6. Netzliste

### 6.1 Versorgungsnetze

| Netz | Angeschlossene Pins |
|---|---|
| +5V | F1.2, U1.1, U2.8, C1.1, C2.1, C3.1, R1.1, R3.1, R5.1, R14.1, JP1.1, J3.1, D1.2, D2.2, D3.2 |
| GND | U1.20, U2.2, U2.5, C1.2, C2.2, C3.2, C4.2, C5.2, C6.2, Q2.E, Q3.E, R12.2, D4.1 (K), J1.1, J1.3, J2.2, J2.4, J2.6, J2.8, J2.10, J3.2, J3.4, J3.6, J3.8, J3.10, J6.1, D1.1, D2.1, D3.1, TP7.1 |
| +15V | J2.9, J3.9, JP2.1 |
| VDRV | JP1.2, JP2.2, R8.1, Q1.S |
| VSENS | R14.2, J1.5, J1.6, TP6.1 |
| +5V_IN | J2.1, F1.1, J6.3 |

F1 ist die 0-Ω-Brücke zwischen +5V_IN und +5V. (Früher als PTC geplant — für die Reihenschaltung von bis zu 10 Modulen entfallen, siehe Änderungshistorie 0.6 und `docs/jlc-bestueckung.md` D-3.)

### 6.2 Signalnetze

| Netz | Angeschlossene Pins |
|---|---|
| RS485_A | U2.6, J2.3, J3.3, JP3.1 |
| RS485_B | U2.7, J2.5, J3.5, R16.2 |
| RS485_TERM | JP3.2, R16.1 |
| RO | U2.1, U1.8 (PB3, USART0 RXD) |
| DI | U2.4, U1.9 (PB2, USART0 TXD) |
| DE | U2.3, U1.11 (PB0, USART0 XDIR) |
| PULSE_BLATT_RAW | J1.10, R1.2, R2.1 |
| PULSE_BLATT | R2.2, C4.1, D1.3, U1.2 (PA4) |
| PULSE_LEER_RAW | J1.8, R3.2, R4.1 |
| PULSE_LEER | R4.2, C5.1, D2.3, U1.3 (PA5) |
| PULSE_NULL_RAW | J1.7, R5.2, R6.1, TP3.1 |
| PULSE_NULL | R6.2, C6.1, D3.3, U1.4 (PA6) |
| TRIAC_DRV | U1.5 (PA7), R7.1, R10.1 |
| Q2_BASE | R7.2, Q2.B |
| PFET_GATE | Q2.C, R8.2, Q1.G |
| TRIAC_CTRL | Q1.D über R9, Q3.C, J1.9, TP4.1 |
| CHAIN_IN_RAW | J2.7, R11.1 |
| CHAIN_IN | R11.2, R12.1, U1.17 (PA1), TP5.1 |
| CHAIN_OUT | U1.18 (PA2), R13.1 |
| CHAIN_OUT_EXT | R13.2, J3.7 |
| UPDI | U1.16 (PA0), J6.2 |
| LED_A | U1.19 (PA3), R15.1 |
| LED_K | R15.2, D4.2 (A) |
| AC1 | J4.1, J5.1, J1.2 |
| AC2 | J4.2, J5.2, J1.4 |
| TP_PB5 | U1.6 (PB5), TP1.1 |
| TP_PB4 | U1.7 (PB4), TP2.1 |

Netz `TRIAC_CTRL` führt Q1.D **über R9** zum Signal: R9.1 an Q1.D, R9.2 am Netz `TRIAC_CTRL`. `VSENS` (6.1) erhält zusätzlich `TP6.1`.

`LED_K` ist der Knoten zwischen R15 und der LED-Anode; die LED-Kathode D4.1 (K) liegt auf GND. Symbol `Device:LED`: Pin 1 = K, Pin 2 = A.

D1–D3 (BAT54S), Zuordnung nach dem KiCad-Symbol `Diode:BAT54S` (Pin 1 = A, Pin 2 = K, Pin 3 = COM): **Pin 1 (A) an GND, Pin 2 (K) an +5V, Pin 3 (COM/Mittelabgriff) am gefilterten Signal.** Gegenüber der Erstfassung korrigiert, siehe `docs/pruefpunkte-t4.md` P-2.

### 6.3 Belegung U1 (ATtiny1616, SOIC-20)

| Pin | Port | Netz |
|---|---|---|
| 1 | VDD | +5V |
| 2 | PA4 | PULSE_BLATT |
| 3 | PA5 | PULSE_LEER |
| 4 | PA6 | PULSE_NULL |
| 5 | PA7 | TRIAC_DRV |
| 6 | PB5 | TP_PB5 → TP1 |
| 7 | PB4 | TP_PB4 → TP2 |
| 8 | PB3 | RO (USART0 RXD) |
| 9 | PB2 | DI (USART0 TXD) |
| 10 | PB1 | offen (Reserve, kein Pad; USART0 XCK) |
| 11 | PB0 | DE (USART0 XDIR) |
| 12 | PC0 | offen (Reserve, kein Pad) |
| 13 | PC1 | offen (Reserve, kein Pad) |
| 14 | PC2 | offen |
| 15 | PC3 | offen |
| 16 | PA0 | UPDI |
| 17 | PA1 | CHAIN_IN |
| 18 | PA2 | CHAIN_OUT |
| 19 | PA3 | LED_A |
| 20 | GND | GND |

> ⚠️ Die Pinbelegung des SOIC-20 vor dem Layout **einmal gegen das Datenblatt** prüfen. Eine Verwechslung von VDD und GND ist der teuerste denkbare Fehler auf dieser Karte.

### 6.4 Testpads

Diese Tabelle ist für die Testpad-Zuordnung **maßgeblich** (Auflösung des früheren Widerspruchs zu 6.3, siehe `docs/pruefpunkte-t4.md` P-1). Nur TP1 und TP2 liegen auf Reserve-GPIOs, TP3–TP7 auf Funktionsnetzen.

| Ref | Netz | Pin | Zweck |
|---|---|---|---|
| TP1 | TP_PB5 | U1.6 (PB5) | Reserve, Firmware-Debug |
| TP2 | TP_PB4 | U1.7 (PB4) | Reserve |
| TP3 | PULSE_NULL_RAW | J1.7 | Untersuchung des Nullimpulses |
| TP4 | TRIAC_CTRL | J1.9 | Messung des Ansteuerpegels, O-2 |
| TP5 | CHAIN_IN | U1.17 (PA1) | Diagnose der Enumeration |
| TP6 | VSENS | J1.5/J1.6 | Einspeisung einer höheren Sensorspannung, falls nötig |
| TP7 | GND | — | Massepunkt für den Tastkopf, direkt neben TP3 und TP4 |

Die Reserve-GPIOs PB0, PC0, PC1, PC2, PC3 (U1 Pin 11–15) bleiben in dieser Fassung **unbeschaltet** — kein Testpad, kein Pad. Wer später Zugriff braucht, führt sie im Layout auf zusätzliche Pads.

---

## 7. Bestückungsvarianten

| Variante | Bedingung | Bestückt | Nicht bestückt |
|---|---|---|---|
| **Q-15** (Vorgabe) | Pin 9 der Anzeige braucht 12–20 V | Q1, Q2, R7, R8, R9 = 4,7 kΩ, JP2 | Q3, R10, JP1 |
| **Q-5** | Pin 9 der Anzeige ist logikpegelfähig | Q1, Q2, R7, R8, R9 = 1,2 kΩ, JP1 | Q3, R10, JP2 |
| **S** | Pin 9 muss nach Masse gezogen werden | Q3, R10 | Q1, Q2, R7, R8, R9, JP1, JP2 |

Die Entscheidung fällt nach O-2 und lässt sich nach der Fertigung durch Umbestücken treffen. Für die Erstserie würde ich alle zehn Karten in **Q-15** bestücken lassen und nach dem Test von Modul 1 gegebenenfalls umrüsten.

| Karte | JP3 (Busabschluss) |
|---|---|
| erste und letzte am Bus | geschlossen |
| alle übrigen | offen |

---

## 8. Layout-Vorgaben

### 8.1 Platine

| Parameter | Wert |
|---|---|
| Abmessungen | 74 × 60 mm |
| Lagen | 2 |
| Materialstärke | 1,6 mm |
| Kupfer | 35 µm (1 oz) |
| Oberfläche | HASL bleifrei genügt |
| Befestigung | 4 × Bohrung 3,2 mm, 4 mm von den Ecken |

74 mm entspricht der Modulbreite ((1 × 75) − 1 mm). Die 60 mm Höhe hält die Karte unter der 100-×-100-mm-Grenze der günstigen Fertigungsstufen bei beiden Anbietern.

### 8.2 Netzspezifische Vorgaben

Stand des Routing-Laufs (v0.7, Betreiber-Vorgabe „alle Bahnen 0,5 mm außer AC"):

| Netz | Leiterbahnbreite | Abstand (DRC) |
|---|---|---|
| AC1, AC2 | **1,5 mm** | 0,5 mm; ≥ 2,0 mm zu Logik ist Handregel, siehe unten |
| alle übrigen Netze (inkl. +5V, +15V, VSENS, VDRV, RS485, CHAIN, Signale) | **0,5 mm** (an SOIC-Pins auf 0,375 mm verjüngt) | 0,2 mm |
| GND | Massefläche F.Cu + B.Cu, Stitching-Raster 5 mm + je ein Via an jedem GND-Pad | 0,2 mm |

- **AC-Führung:** AC1/AC2 laufen von J4 über J5 nach J1, räumlich getrennt vom
  Bereich um U1/U2. Die ≥ 2,0-mm-Vorgabe zu Logiknetzen lässt sich am
  2,54-mm-Raster von J1/J4/J5 **nicht** halten und ist keine DRC-Regel. Q1–Q3
  und R7–R10 wurden aus dem AC-Korridor nach rechts gerückt; danach hält die
  AC-Bahn ≥ 0,55 mm Kupferabstand zu jeder Logikbahn und ≥ 2,4 mm zu jedem
  Logik-Pad. Bei 1 A / 35 µm ergeben 1,5 mm eine Erwärmung ≪ 10 K.
- **+5V bei 0,5 mm:** stromtragfähig (~1,3 A nach IPC-2221), aber der
  Spannungsabfall der Durchgangsschiene über 10 Module steigt gegenüber einer
  breiten Bahn deutlich (grob 0,3 V on-board plus Stecker und Flachbandkabel).
  Konsequenz siehe `docs/jlc-bestueckung.md` D-5.

### 8.3 Weitere Hinweise

- C1 und C2 direkt an den Versorgungspins der jeweiligen ICs platzieren, Anbindung über kurze Stiche an eine durchgehende Massefläche auf der Rückseite.
- RS485_A und RS485_B als Paar mit konstantem Abstand führen, keine Stichleitungen. R16 und JP3 nahe an J2 setzen.
- C4, C5, C6 nahe an den Portpins von U1 platzieren, die Widerstände R2, R4, R6 nahe an J1. Das ist die wirksame Reihenfolge für den Tiefpass.
- Massefläche auf **beiden** Lagen, unterbrochen nur im Bereich der AC-Führung.
- Silkscreen: Pin 1 aller Steckverbinder deutlich markieren, JP1/JP2 mit „5V" und „15V" beschriften, JP3 mit „TERM".
- Beschriftungsfeld für die Modulnummer vorsehen, auch wenn die Adresse per Enumeration vergeben wird — es hilft bei der Fehlersuche.
- **Platine schwarz, Bestückungsdruck weiß.** Im Lagenaufbau der `.kicad_pcb`
  gesetzt (Maske „Black" / Silk „White"); bei JLCPCB die passende Bestelloption
  wählen. Maker-Kennzeichnung (GitHub-Marke + „TenOfNine") auf der Rückseite.

### 8.4 Fertigung

| Anbieter | Hinweis |
|---|---|
| JLCPCB | Bestückung nur sinnvoll, wenn U1 im Teilekatalog verfügbar ist. Vorab prüfen. U2 ist als C94206 gelistet. Andernfalls U1 nachbestücken lassen oder von Hand löten — SOIC-20 im 300-mil-Gehäuse ist gut handlötbar. |
| PCBWay | Flexibler bei Fremdbauteilen, dafür bei Kleinserien meist etwas teurer. |

Bei zehn Karten würde ich fünfzehn fertigen lassen. Der Aufpreis ist gering und du hast Reserve für Umbestückungsversuche.

---

## 9. Prüfliste vor der ersten Inbetriebnahme

1. Durchgang J1 gegen die Anzeigenplatine prüfen, Pin für Pin. Insbesondere sicherstellen, dass J1.2 und J1.4 auf den 42-V~-Pins der Anzeige landen und nicht auf der Versorgung. J1 ist eine **nicht kodierte Buchsenleiste** — die Drehlage der aufgesteckten Karte zuerst gegen Pin 1 der Anzeige kontrollieren (siehe 4.1 und `docs/pruefpunkte-j1-buchsenleiste.md`).
2. Widerstand zwischen +5V und GND messen. Ein Wert unter 1 kΩ deutet auf einen Bestückungsfehler.
3. Widerstand zwischen AC1 und GND messen. Muss hochohmig sein, die Motorspannung ist potenzialfrei.
4. Prüfen, dass genau einer von JP1 und JP2 geschlossen ist.
5. Karte allein mit 5 V versorgen, Stromaufnahme messen. Erwartet werden unter 20 mA ohne aktive Buskommunikation.
6. UPDI-Verbindung herstellen und die Device-ID auslesen, bevor das erste Mal Firmware geschrieben wird.
7. Erst danach die Anzeige anstecken und mit Teststufe 1 nach Kapitel 10.1 der Spezifikation beginnen.

---

## 10. Offene Punkte mit Einfluss auf dieses Dokument

| Nr | Punkt | Auswirkung auf den Schaltplan |
|---|---|---|
| O-2 | Ansteuerpegel an Pin 9 | Bestimmt Bestückungsvariante nach Kapitel 7 und den Wert von R9. Das Layout ist davon unabhängig, alle Positionen sind vorgesehen. |
| O-5 | Zulässiger Senkenstrom der Hall-Sensoren | Bei einem sehr schwachen Ausgangstreiber sind R1, R3, R5 auf 22 kΩ zu erhöhen. |
| O-5b | Ausreichende Sensorspannung bei 5,0 V | Falls nicht, R14 entfernen und VSENS über TP6 aus einer 6-V-Quelle speisen. |

---

## 11. Änderungshistorie

| Version | Datum | Änderung |
|---|---|---|
| 0.1 | 27.08.2026 | Erstfassung auf Basis der Spezifikation v0.3. |
| 0.2 | 28.08.2026 | T4: Netzliste in KiCad-Schaltplan überführt. Zwei Widersprüche in Kapitel 6 aufgelöst (Details und offene Gegenprüfung in `docs/pruefpunkte-t4.md`): **P-1** Testpad-Zuordnung — 6.4 ist maßgeblich, TP3–TP5 liegen auf Funktionsnetzen, die Reserve-GPIOs PB0/PC0/PC1/PC2/PC3 bleiben unbeschaltet; 6.3 entsprechend gefasst. **P-2** Klemmdioden D1–D3 (BAT54S) — Pinbelegung auf das KiCad-Symbol und eine funktionsfähige Clamp-Topologie umgestellt: Pin 1 (A) → GND, Pin 2 (K) → +5V, Pin 3 (COM) → Signal. Testpad-Netze TP1–TP7 und `LED_K` in die Netzliste aufgenommen. |
| 0.3 | 28.08.2026 | **P-3** (`docs/pruefpunkte-t7.md`): RS-485-Anschluss auf die USART0-Standard-MUX-Position des ATtiny1616 korrigiert. RO an PB3 (Pin 8, war PB1), DE an PB0 (Pin 11, war PB3), DI an PB2 unverändert. PB1 (Pin 10) wird neuer unbeschalteter Reserve-Pin. Netze `RO`/`DE` und die Pinbelegung 6.3 entsprechend. ERC weiter 0/0. |
| 0.4 | 31.08.2026 | JLCPCB-Bestückung vorbereitet (`docs/jlc-bestueckung.md`): LCSC-Nummern und Basic/Extended-Einordnung, zweite Anschlussbild-Prüfung aller Symbole (ohne Befund). **R16 von 1206 auf 0805** (D-1) — 120 Ω ist bei JLCPCB nur in 0805 ein Basic Part, Verlustleistung unkritisch. Schaltplan und PCB neu erzeugt, ERC 0/0. |
| 0.5 | 31.08.2026 | **J1 von Wannenstecker auf Buchsenleiste 2×5** (Referenz BKL 10120960). Grund: die Daughter Card wird board-to-board direkt auf den Pfostenstecker der Anzeigenplatine gesteckt; ein Wannenstecker (Stifte im Kragen) passt dort nicht. Pinbelegung 4.1 unverändert. Neu: J1 ist nicht mehr mechanisch kodiert → erweiterter Verpol-Hinweis in 4.1, Prüfliste 9.1, offener Punkt `docs/pruefpunkte-j1-buchsenleiste.md`. Footprint `Connector_PinSocket_2.54mm:PinSocket_2x05_P2.54mm_Vertical`. ERC 0/0. |
| 0.6 | 31.08.2026 | **F1 von PTC 0,5 A auf 0-Ω-Brücke** (`docs/jlc-bestueckung.md` D-3): F1 liegt im +5V-Durchgangspfad J2 → F1 → J3; bei 10 Modulen in Reihe läge der Kettenstrom über dem PTC-Auslösewert. Fail-Safe übernehmen Watchdog und Laufzeitgrenze (Spez. 8). Symbol `krone:R`, Wert `0R`, Footprint `Resistor_SMD:R_1206_3216Metric`, LCSC `C17888` (Basic). Stückliste 3.2, Blockschaltbild 5.1, Netzliste-Notiz angepasst. ERC 0/0. |
| 0.7 | 01.09.2026 | Routing-Lauf (Betreiber-Vorgaben): **alle Leiterbahnen 0,5 mm außer AC1/AC2 (1,5 mm)** — Abschnitt 8.2 entsprechend gefasst, Hinweis auf den +5V-Spannungsabfall bei 0,5 mm über 10 Module (`docs/jlc-bestueckung.md` D-5). Q1–Q3/R7–R10 aus dem AC-Korridor gerückt (AC ↔ Logikbahn danach ≥ 0,55 mm). **Platine schwarz / Druck weiß** im Lagenaufbau. Maker-Kennzeichnung (GitHub-Marke + „TenOfNine") auf B.SilkS. Schaltplan unverändert, ERC 0/0. |

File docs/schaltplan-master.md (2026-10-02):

# Schaltplan Zentralsteuerung (Master) — KRONE REW Fallblattanzeige

| Feld | Wert |
|---|---|
| Baugruppe | Zentralsteuerung / RS-485-Master, Spezifikation Kapitel 7 |
| CPU | ESP32-C3 Super Mini (Aftermarket-Modul), steckbar in Buchsenleisten |
| Revision | 0.2 (10.09.2026) |
| Erzeugt von | `tools/gen_master_sch.py` → `hardware/master/master.kicad_sch` |
| Projektbibliothek | `hardware/master/symbols/krone_master.kicad_sym` (`tools/build_krone_master_symbols.py`) |
| Status | ERC 0/0, PCB geroutet (DRC 0 Fehler). Symbolprüfung `docs/symbolpruefung-master.md` **freigegeben** (01.09.2026; AO3401A + SM712 nachgetragen). M-3 (CHAIN-Pegel): U3 wird bestückt (Betreiber-Entscheidung). M-2 (Boost) an O-2 gebunden. |

**Rev. 0.2 (10.09.2026):** Verpolschutz am 5-V-Eingang (P-FET Q1 + R8) und
RS-485-TVS am Bus (D2). CHAIN-Pegelwandler U3 als feste Bestückung bestätigt. Für
U1 keine Edge.Cuts-Aussparung — das Modul ist zum Flashen aus den Buchsenleisten
entnehmbar. PCB inkrementell geroutet (`tools/patch_master_pcb.py`), ERC 0/0,
DRC 0/0, Fertigungspaket regeneriert.

**Verbindliche Quelle** für Netzliste und Bestückung ist Kapitel 6 dieses
Dokuments. Bei Widerspruch zur Spezifikation gilt die Netzliste (analog
`docs/schaltplan-daughtercard.md`).

---

## 1. Konventionen

- Bezeichner englisch, Fließtext deutsch (CLAUDE.md).
- Netznamen entstehen aus lokalen Pin-Labels; gleiche Namen = gleiches Netz.
- Alle Kleinteile 0805, ICs SOIC-8 / SOT-23-5. Der Master ist ein **Einzelstück**;
  die komplette Handbestückung ist zumutbar, JLCPCB-SMT ist optional.
- Die **42 V~ kommen nicht auf diese Platine.** Der Ringkerntrafo 2×18 V wird
  extern in Reihe geschaltet und direkt an die Schraubklemme der ersten
  Daughter Card verdrahtet (Spez. 8.1). Auf dem Master gibt es kein AC-Netz.

---

## 2. Blockschaltbild

```
  +5 V           Q1 AO3401A
  Netzteil       Verpolschutz          ESP32-C3 Super Mini (U1, steckbar)
  (J1)           (P-FET, High-Side)    ┌──────────────────────────────┐
    │ +5V_RAW    S ──┬── D  +5V_IN     │ 5V ─ Onboard-LDO ─ 3V3-Pin   │
    ├────────────────┤   │             │ UART1: TX(GPIO3) RX(GPIO4)    │
    │   R8 100k ─────┘   │             │ DE(GPIO10)  CHAIN(GPIO5)      │
    │   (G→GND, V_GS)    │             │ LED(GPIO6)   RSV GPIO0/1/7    │
    │                    ├── C3 47µF   └──┬─────┬──────┬──────┬────────┘
    │                    │               3V3  TX/RX   DE    CHAIN
    │                  FB1 60R ── +5V ─────┼──────┼─────┼──── U3 VCC (5 V)
    │                                 U3 VCC │      │     │       │
    │  +3V3 ── U2 (TP8485E) VCC ────── C4/C2 │      │     │   ┌───┴──┐ 74LVC1G17
    │            /RE = GND                   │      │     │   │  U3  │ 3,3→5 V
    │       DI ──┘   RO ── GPIO4             │      │     │   └───┬──┘ (nicht inv.)
    │       DE ──────────────────────────── GPIO10  │  R4 10k↓GND │
    │       A ─┬─ R2 680Ω → +3V3   (Fail-Safe-Bias, nur am Master) │
    │       B ─┤─ R3 680Ω → GND                                    │
    │         ├─ R1 120Ω  (Abschluss, fest)                        │
    │         ├─ D2  SM712: Pin1↔GND / Pin2↔GND je 7 V/12 V (TVS)  │
    │         └─ A,B ──────────────────────────────► J2 Ader 3 / 5 │
    │                              CHAIN ─ R5 100Ω ─► J2 Ader 7 ◄──┘
    ├─ +5V_IN ─ JP1 (offen / +5V / +15V) ──────────► J2 Ader 9
    └─ +5V_IN ─────────────────────────────────────► J2 Ader 1 (+5V)
                                                     J2 Ader 2/4/6/8/10 = GND

  Step-up 5 V→15 V (J4, Modul, DNP) ── +15V ── JP1 Pin 3   (nur falls O-2 Deutung 1)
```

---

## 3. Stückliste

### 3.1 Aktive Bauteile

| Ref | Bauteil | Gehäuse | LCSC | Anmerkung |
|---|---|---|---|---|
| U1 | ESP32-C3 Super Mini | Modul 18×22,5 mm, 2×8 Header | — | Aftermarket, steckbar; Einbaulage siehe `symbolpruefung-master.md` |
| U2 | TP8485E-SR | SOIC-8 | C94206 | RS-485, 3,3 V, Full-Fail-Safe, /RE fest auf GND |
| U3 | 74LVC1G17 | SOT-23-5 | C19829593 | CHAIN 3,3 V → 5 V, Schmitt-Buffer. Feste Bestückung (M-3 entschieden) |
| Q1 | AO3401A | SOT-23 | C15127 | Verpolschutz 5-V-Eingang, P-Kanal High-Side (−30 V, −4 A, R_DS(on) ≈ 55 mΩ). JLC Basic |
| D1 | LED grün | 0805 | C2297 | Betriebsanzeige (GPIO6) |
| D2 | SM712 / PSM712-LF-T7 | SOT-23 | C32677 | RS-485-TVS-Array am Bus, 7 V / 12 V asymmetrisch (−7…+12 V). JLC Basic. Pinbelegung `symbolpruefung-master.md` |

### 3.2 Passive Bauteile

| Ref | Wert | Gehäuse | LCSC | Funktion |
|---|---|---|---|---|
| R1 | 120 Ω | 0805 | C17437 | RS-485-Abschluss, **fest** (Spez. 7.1) |
| R2, R3 | 680 Ω | 0805 | C17798 | Fail-Safe-Bias A→+3V3 / B→GND (Spez. 5.1) |
| R4 | 10 kΩ | 0805 | C17414 | DE-Pulldown (kein Bus-Treiben im Reset) |
| R5 | 100 Ω | 0805 | C17408 | CHAIN-Serienwiderstand zum Bus |
| R6 | 1 kΩ | 0805 | C17513 | Vorwiderstand Status-LED |
| R7 | 0 Ω | 0805 | — | **DNP.** Reserve-Bypass von U3, falls sich 3,3 V direkt doch als ausreichend erweist (M-3) |
| R8 | 100 kΩ | 0805 | C149504 | V_GS-Widerstand für Q1 (Gate → Source, definierter Aus-Zustand) |
| C1, C2, C4 | 100 nF | 0805 | C49678 | Abblockung U2 / U3 / U1-5V |
| C3 | 47 µF / 25 V | 1206 | C76659 | Bulk am 5-V-Eingang (hinter Q1) |
| C5 | 10 µF | 0805 | C15850 | Stützkondensator +3V3 |
| FB1 | 60 Ω @ 100 MHz, 3,5 A | 0805 | C18305 | Ferrit, filtert **nur** den lokalen Logikzweig |

### 3.3 Steckverbinder / Mechanik (Handlötung)

| Ref | Bauteil | Funktion |
|---|---|---|
| — | 2× Buchsenleiste 1×8, 2,54 mm | Sockel für U1 (Modul entnehmbar) |
| J1 | Schraubklemme 2-polig, RM 5,08 mm | +5 V vom Netzteil |
| J2 | Wannenstecker 2×5, 2,54 mm | Bus zur ersten Daughter Card (Ader-Belegung Spez. 5.2) |
| J3 | Stiftleiste 1×4, 2,54 mm | Reserve: GPIO0, GPIO1, GPIO7, GND |
| J4 | Stiftleiste 1×4, 2,54 mm | Aufwärtswandler-Modul 5 V→15 V (**DNP**, siehe 5.6) |
| JP1 | Lötbrücke 3-Wege | Ader 9 = offen (Vorgabe) / +5 V / +15 V |
| H1–H4 | Bohrung 3,2 mm | Befestigung M3 |
| TP1–TP7 | Ø 1,5 mm | RS485_A, RS485_B, CHAIN_BUS, +3V3, +15V, GND, ADER9 |

---

## 4. Steckverbinder

### 4.1 J1 — Versorgung

| Pin | Signal |
|---|---|
| 1 | +5 V vom **separaten** Schaltnetzteil 5 V / 2 A (Spez. 8.2). Nicht mit dem 42-V~-Kreis verbunden. |
| 2 | GND |

Reihenfolge J1 → **Q1 (Verpolschutz)** → `+5V_IN` → C3 (Bulk) → FB1 (Ferrit) →
lokale Logik. Der Bus (J2.1) und der Ader-9-Jumper hängen an der geschützten,
aber **ungefilterten** Schiene `+5V_IN`, damit der Ferrit nicht den Kettenstrom
(bis ~2 A bei 10 Modulen) führt. `+5V_RAW` ist nur das kurze Stück Klemme → Q1.

**Verpolschutz.** Q1 (AO3401A, P-Kanal, High-Side): Source an `+5V_RAW`, Drain an
`+5V_IN`, Gate an GND, R8 = 100 kΩ Gate→Source. Bei richtiger Polung zieht
V_GS = −5 V den FET voll durch (R_DS(on) ≈ 55 mΩ → bei 2 A ~0,1 V Abfall, ~0,2 W).
⚠️ **Bekannter Mangel Rev. 0.2 (Issue #36):** In dieser Einbaulage (Source an
der Klemme) leitet die Body-Diode bei vertauschter Klemme – der Verpolschutz ist
wirkungslos. Die 5-V-Klemme daher nicht verpolen und den Verpolfall an Rev.-0.2-
Platinen nicht testen. Korrektur für die nächste Revision: Drain an `+5V_RAW`,
Source an `+5V_IN`, Gate an GND (R8 dann zwischen Gate und Source). Die
ursprüngliche Aussage „FET und Body-Diode sperren bei Verpolung" war falsch. V_GS = 5 V liegt weit innerhalb ±12 V, kein
Gate-Zener nötig.

### 4.2 J2 — Bus zur ersten Daughter Card

Wannenstecker 2×5, Belegung **identisch zu Daughter-Card-J2/J3** (Spez. 5.2):

| Ader | Signal | Ader | Signal |
|---|---|---|---|
| 1 | +5 V | 2 | GND |
| 3 | RS-485 A | 4 | GND |
| 5 | RS-485 B | 6 | GND |
| 7 | CHAIN | 8 | GND |
| 9 | +15 V (Triac-Treiber, nur falls O-2) | 10 | GND |

Der 120-Ω-Abschluss (R1) sitzt fest am Master (ein Busende). Das andere Ende ist
die letzte Daughter Card mit gesetztem JP3.

### 4.3 J3 — Reserve

| Pin | Signal | Hinweis |
|---|---|---|
| 1 | GPIO0 | ADC1, frei; z. B. Helligkeitssensor für Auto-Dimmen |
| 2 | GPIO1 | ADC1, frei |
| 3 | GPIO7 | frei |
| 4 | GND | |

### 4.4 J4 — Aufwärtswandler-Modul (DNP)

Steckplatz (1×4) für ein handelsübliches Boost-Modul (z. B. MT3608-Breakout):

| Pin | Signal |
|---|---|
| 1 | +5 V (Eingang) |
| 2 | GND |
| 3 | +15 V (Ausgang) |
| 4 | GND |

Bleibt unbestückt, bis O-2 zeigt, dass die Anzeige an Pin 9 mehr als 5 V braucht.
Dann Modul-Trimmer auf **15,0 V** stellen, einstecken, JP1 auf +15 V.

---

## 5. Schaltungsblöcke

### 5.1 Versorgung

- Eingang 5 V an J1 von einem **eigenen** 5-V-Schaltnetzteil. Der 42-V~-Kreis
  (Motoren) und der 5-V-Kreis (Logik) bleiben vollständig getrennt — keine
  gemeinsame Ader, kein gemeinsamer Trafo (Spez. 8, CLAUDE.md Regel 4).
- **Q1 (Verpolschutz)** direkt hinter J1, siehe 4.1. Alles ab `+5V_IN` liegt
  hinter dem FET.
- Die ESP32-C3-Super-Mini versorgt sich über ihren **5V-Pin** aus dieser Schiene
  und erzeugt 3,3 V mit ihrem **Onboard-LDO** (bis ~500 mA).
- Der **3V3-Pin des Moduls** speist U2 (TP8485E), die Bias-Kette und C5 zurück
  ins Trägerboard. Kein separater Regler auf dem Master.
- FB1 (Ferrit) + C4/C2 entkoppeln den Logikzweig (`+5V`) von der Busschiene.
- Symbol-Pintyp: 5V/GND = `power_in`, 3V3 = `power_out` → PWR_FLAG auf
  `+5V_RAW`, `+5V_IN`, `+5V`, `GND` und `+15V` (Boost-Ausgang).

### 5.2 RS-485-Anbindung

- U2 = TP8485E-SR bei **3,3 V** (Spez. 7.1). Master und Modul teilen sich den
  Bausteintyp trotz unterschiedlicher Logikspannung (3–5,5 V-Bereich).
- `/RE` fest auf GND → Dauerempfang; die Firmware verwirft das Sendeecho.
- `DE` an GPIO10, zusätzlich R4 = 10 kΩ nach GND: bei Reset/Boot treibt der
  Transceiver den Bus nicht.
- ESP32-C3 hat nur zwei UARTs; UART0 = USB-C-Konsole. **RS-485 läuft auf UART1**
  (per GPIO-Matrix frei auf GPIO3/GPIO4/GPIO10 gelegt). In der Firmware umgesetzt
  (T12, `firmware/master/`): `pio run -e esp32c3` kompiliert, Host-Tests grün.
- Abschluss R1 = 120 Ω fest, Bias R2/R3 = 2 × 680 Ω (A→+3V3, B→GND).
- **D2 (RS-485-TVS)** im A/B-Pfad zwischen Bias und J2: SM712-Profil,
  7 V Arbeitsspannung Richtung GND und 12 V Richtung Leitung — deckt den
  RS-485-Gleichtaktbereich −7…+12 V ab. Klemmt ESD/EFT/Surge, bevor sie U2
  erreichen. `Pin 1 → RS485_A, Pin 2 → RS485_B, Pin 3 → GND`
  (`symbolpruefung-master.md`, gegen Bourns-CDSOT23-SM712-Datenblatt geprüft).

### 5.3 CHAIN-Pegelwandler

Die Karte-zu-Karte-CHAIN-Leitung ist 5-V-Logik (ATtiny push-pull). Nur der erste
Link Master→Karte 1 ist 3,3 V. U3 = 74LVC1G17 (Schmitt-Buffer, aus +5V versorgt,
nicht invertierend) hebt GPIO5 auf 5 V. R5 = 100 Ω in Serie zum Bus.

**M-3 entschieden (Betreiber, 10.09.2026):** U3 wird bestückt. Der ATtiny1616
erkennt 3,3 V am UPDI/GPIO-Eingang nicht garantiert als High (V_IH bis 0,8·VDD =
4,0 V bei 5-V-Betrieb) — der Pegelwandler bleibt. **R7 (0 Ω)** bleibt als
unbestückter Reserveplatz, falls ein Tisch-Test das doch widerlegt.

### 5.4 Status-LED

GPIO6 → R6 (1 kΩ) → D1 (grün) → GND. Zusätzlich hat das Modul selbst eine LED an
GPIO8 (im eingebauten Zustand verdeckt).

### 5.5 Ader 9 / Triac-Treiberspannung

JP1 (3-Wege-Lötbrücke): Mitte = Ader 9 (J2.9). Pin 1 = +5V_IN, Pin 3 = +15V.
Auslieferzustand **offen** — Ader 9 unbeschaltet, bis O-2 entschieden ist.

### 5.6 Aufwärtswandler (DNP)

J4 als Steckplatz für ein Boost-Modul, Eingang +5V_IN, Ausgang +15V → JP1 Pin 3.
Kein diskreter Regler auf dem Master (spart die Datenblatt-Pinprüfung eines
Boost-ICs; Regel 1). Falls ein diskreter Aufbau gewünscht wird, ist er als
eigener Revisionsschritt zu ergänzen.

---

## 6. Netzliste

Quelle: `tools/gen_master_sch.py`, Dict `NETS`. 20 Netze, 89 Pinverbindungen.

### 6.1 Versorgungsnetze

| Netz | Knoten |
|---|---|
| `+5V_RAW` | J1.1, Q1.2, R8.2 |
| `+5V_IN` | Q1.3, C3.1, FB1.1, J2.1, JP1.1, J4.1 |
| `+5V` | FB1.2, U1.1, C4.1, C2.1, U3.5 |
| `+3V3` | U1.3, U2.8, C1.1, C5.1, R2.1, TP4.1 |
| `+15V` | J4.3, JP1.3, TP5.1 |
| `GND` | J1.2, U1.2, U2.2, U2.5, U3.3, Q1.1, R8.1, D2.3, C1.2, C2.2, C3.2, C4.2, C5.2, R3.2, R4.2, D1.1, J2.2/4/6/8/10, J3.4, J4.2, J4.4, TP6.1 |

PWR_FLAG: `+5V_RAW`, `+5V_IN`, `+5V`, `GND`, `+15V`.

Q1 (AO3401A): Pin 1 = G → GND, Pin 2 = S → `+5V_RAW`, Pin 3 = D → `+5V_IN`.

### 6.2 Signalnetze

| Netz | Knoten | Bemerkung |
|---|---|---|
| `RS485_A` | U2.6, R1.1, R2.2, D2.1, J2.3, TP1.1 | D2 = SM712 Pin 1 |
| `RS485_B` | U2.7, R1.2, R3.1, D2.2, J2.5, TP2.1 | D2 = SM712 Pin 2 |
| `RO` | U2.1, U1.4 | GPIO4 (UART1 RX) |
| `DI` | U2.4, U1.5 | GPIO3 (UART1 TX) |
| `DE` | U2.3, U1.14, R4.1 | GPIO10 |
| `CHAIN_GPIO` | U1.9, U3.2, R7.1 | GPIO5 → Buffer-Eingang / Bypass |
| `CHAIN_OUT` | U3.4, R5.1, R7.2 | Buffer-Ausgang |
| `CHAIN_BUS` | R5.2, J2.7, TP3.1 | 5-V-Pegel zum Bus |
| `LED_DRV` | U1.10, R6.1 | GPIO6 |
| `LED_A` | R6.2, D1.2 | |
| `ADER9` | JP1.2, J2.9, TP7.1 | Ader 9 (offen / +5V / +15V) |
| `IO0_RSV` | U1.8, J3.1 | GPIO0 |
| `IO1_RSV` | U1.7, J3.2 | GPIO1 |
| `IO7_RSV` | U1.11, J3.3 | GPIO7 |

### 6.3 Belegung U1 (ESP32-C3 Super Mini, 2×8)

Pinnummern = Footprint-Pads. Rechte Reihe (Pad 1..8) = 5V-Seite, linke Reihe
(Pad 9..16). **Einbaulage:** USB-C oben, Antenne unten, 5V-Pad rechts oben.

| Pad | Signal (Modul-Silk) | Netz | Funktion |
|---|---|---|---|
| 1 | 5V | +5V | Versorgung (hinter Q1 + FB1, Onboard-LDO) |
| 2 | GND | GND | |
| 3 | 3V3 | +3V3 | 3,3-V-Ausgang des Moduls → Transceiver |
| 4 | GPIO4 | RO | UART1 RX ← U2 |
| 5 | GPIO3 | DI | UART1 TX → U2 |
| 6 | GPIO2 | — | NC (Strapping) |
| 7 | GPIO1 | IO1_RSV | Reserve → J3.2 |
| 8 | GPIO0 | IO0_RSV | Reserve → J3.1 |
| 9 | GPIO5 | CHAIN_GPIO | → U3 |
| 10 | GPIO6 | LED_DRV | Status-LED |
| 11 | GPIO7 | IO7_RSV | Reserve → J3.3 |
| 12 | GPIO8 | — | NC (Strapping, Onboard-LED) |
| 13 | GPIO9 | — | NC (Strapping, BOOT-Taster) |
| 14 | GPIO10 | DE | Sende-Freigabe U2 |
| 15 | GPIO20 | — | NC (UART0 RX, USB-Konsole) |
| 16 | GPIO21 | — | NC (UART0 TX, USB-Konsole) |

### 6.4 Testpads

| Ref | Netz |
|---|---|
| TP1 | RS485_A |
| TP2 | RS485_B |
| TP3 | CHAIN_BUS |
| TP4 | +3V3 |
| TP5 | +15V |
| TP6 | GND |
| TP7 | ADER9 |

---

## 7. Bestückungsvarianten

| Variante | Bestückt | Wann |
|---|---|---|
| **Standard** | U3, Q1, R8, D2 bestückt; R7 nicht | Auslieferzustand |
| CHAIN direkt (M-3-Reserve) | R7 (0 Ω), U3 nicht | nur falls ein Tisch-Test zeigt, dass 3,3 V die ATtiny-Eingänge sicher schalten (unwahrscheinlich, siehe 5.3) |
| Ader 9 = +15 V (O-2 Deutung 1) | J4-Boost-Modul, JP1 auf Pin 3 | wenn die Anzeige an Pin 9 > 5 V braucht |
| Ader 9 = +5 V (O-2 Deutung 2) | JP1 auf Pin 1 | wenn 5 V an Pin 9 genügen |

---

## 8. Layout-Vorgaben

### 8.1 Platine

| Feld | Wert |
|---|---|
| Maß | 68 × 54 mm, 2 Lagen, 1,6 mm FR4, 35 µm Cu, HASL bleifrei |
| Farbe | Lötstoppmaske schwarz, Bestückungsdruck weiß |
| Befestigung | 4 × Bohrung 3,2 mm, 4 mm von den Ecken |
| Maker-Mark | GitHub-Marke + „TenOfNine" auf B.SilkS |

### 8.2 Netzklassen

| Klasse | Bahnbreite | Netze |
|---|---|---|
| Power | 0,8 mm | +5V, +5V_RAW, +5V_IN, +3V3, +15V, ADER9 |
| Default | 0,5 mm | alle Signale |
| GND | — | Massefläche F.Cu + B.Cu, Stitching 5 mm |

Kein AC-Netz. `tools/route_master.py` (FreeRouting 2.3.0 + `finish_routes.py` +
Masseflächen) routet zweilagig; DRC 0/0.

### 8.3 ESP32-C3-Modul (U1)

- Buchsenleisten, Modul entnehmbar. USB-C/BOOT/RST an der Oberkante, überragt die
  Platinenkante (im eingesteckten Zustand bedienbar).
- **Antennenbereich an der Unterkante des Moduls: keine Kupferfläche.** Der
  Footprint enthält ein Keepout (Copperpour + Vias verboten, Pads/Tracks
  erlaubt). Wenn möglich das Modul so einbauen, dass die Antenne über die
  Platinenkante ragt.
- ⚠️ **Sicherheitskritisch:** eine spiegelverkehrte Modul-Fläche vertauscht
  5V/GND und zerstört den ESP32-C3. Vor dem Routen `symbolpruefung-master.md`
  freigeben und die KiCad-3D-Ansicht prüfen (analog J1-M der Daughter Card).

---

## 9. Prüfliste vor der ersten Inbetriebnahme

- [ ] `symbolpruefung-master.md` freigegeben (M-1: ESP32-C3-Pinbelegung ↔ Silk)
- [ ] U1-Footprint in der 3D-Ansicht gegen ein echtes Modul gehalten (5V rechts oben)
- [ ] J2-Belegung gegen Daughter-Card-J2/J3 geprüft (Spez. 5.2)
- [ ] JP1 offen (Ader 9 unbeschaltet) bis O-2 entschieden
- [ ] Spannung an J1: 5,0–5,5 V, verpolungssicher angeklemmt
- [ ] 3V3-Pin des Moduls misst 3,3 V, U2 VCC = 3,3 V
- [ ] Vor dem Aufstecken von U1: kein Kurzschluss +5V ↔ GND ↔ +3V3

---

## 10. Offene Punkte

| Nr | Punkt | Wirkung | Status |
|---|---|---|---|
| M-1 | ESP32-C3-Super-Mini Symbol/Footprint ↔ Board-Silk + Einbaulage | Gate fürs Layout | ✅ freigegeben 01.09.2026 (`symbolpruefung-master.md`); Sichtkontrolle am Render durch den Betreiber |
| M-2 | Aufwärtswandler-Modul | J4 bleibt DNP | wartet auf O-2 |
| M-3 | CHAIN 3,3 V → 5 V: U3 nötig oder R7-Brücke | Bestückungsvariante | auf dem Tisch zu prüfen |
| O-2 | 5 V oder 12–20 V an Anzeige-Pin 9 (Spez.) | JP1-Stellung, Boost | offen |
| T12 | Master-Firmware auf ESP32-C3 portieren (UART1, GPIO-Konstanten) | Firmware | ✅ kompiliert (`pio run -e esp32c3`), am Gerät noch nicht getestet |

---

## 11. Änderungshistorie

| Rev | Datum | Änderung |
|---|---|---|
| 0.1 | 01.09.2026 | Erstfassung. ESP32-C3 Super Mini als Master-CPU (Buchsenleisten), 5-V-Eingang, TP8485E bei 3,3 V, Fail-Safe-Bias + fester 120-Ω-Abschluss, CHAIN-Pegelwandler 74LVC1G17 (M-3), Step-up-Steckplatz DNP (M-2 / O-2). Schaltplan + geroutete PCB generiert (`tools/gen_master_*.py`, `tools/route_master.py`), ERC 0/0, DRC 0/0. |

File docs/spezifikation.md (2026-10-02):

# Technische Spezifikation: Steuerung für KRONE REW Fallblattanzeige

---

## 1. Dokumentübersicht

| Feld | Wert |
|---|---|
| Titel | Steuerung für KRONE REW Fallblattanzeige (Palettenmodulreihe A, 40 Blatt) |
| Version | 0.29 |
| Datum | 02.10.2026 |
| Status | Entwurf — enthält offene Punkte, siehe Kapitel 11. Änderungen seit v0.8 in Anhang D. |
| Dokumenttyp | Technische Spezifikation (TSD) |

**Hinweis zur Lesart:** Punkte, die noch nicht durch Messung oder Dokumentation belegt sind, sind mit ⚠️ markiert. Wo eine Entscheidung von einer ausstehenden Messung abhängt, sind beide Varianten ausgearbeitet.

---

## 2. Systemüberblick

### 2.1 Ziel

Ersatz der originalen KRONE-Anzeigersteuerung und der Palettensteuerungen (PST, Zeichnung 6412 2 100-00, IC HMCS44C) durch eine Eigenbau-Lösung. Die mechanischen Anzeigenmodule und deren Leiterplatten (6281 3 160-00) bleiben unverändert und werden weiterverwendet.

### 2.2 Architektur

```
                    ┌──────────────────────────────┐
   230 V ~ ─────────┤ Netzteilbaugruppe            │
                    │  · Ringkerntrafo 2x18 V      │──── 42 V~ (Motoren)
                    │  · Netzteil 5 V / 2 A        │──── 5 V (Logik + Sensoren)
                    │  · optional 15 V (Ader 9)    │──── 15 V (Triac-Treiber)
                    └──────────────────────────────┘
                                   │
                    ┌──────────────┴───────────────┐
                    │ Zentralsteuerung (ESP32-C3)  │
                    │  · WLAN, Web-UI, REST, MQTT  │
                    │  · NTP-Uhr                   │
                    │  · RS-485-Master             │
                    └──────────────┬───────────────┘
                                   │  RS-485 half duplex + CHAIN
        ┌──────────┬───────────────┼───────────────┬──────────┐
        │          │               │               │          │
   ┌────┴────┐ ┌───┴─────┐    ┌────┴────┐     ┌────┴────┐    ...
   │ DC #1   │ │ DC #2   │    │ DC #3   │     │ DC #n   │
   │ATtiny   │ │ATtiny   │    │ATtiny   │     │ATtiny   │
   └────┬────┘ └───┬─────┘    └────┬────┘     └────┬────┘
        │ 2x5      │               │               │
   ┌────┴────┐ ┌───┴─────┐    ┌────┴────┐     ┌────┴────┐
   │Anzeige 1│ │Anzeige 2│    │Anzeige 3│     │Anzeige n│
   └─────────┘ └─────────┘    └─────────┘     └─────────┘

   DC = Daughter Card (eine je Anzeigenmodul)
```

### 2.3 Auslegung

| Parameter | Wert |
|---|---|
| Anzahl Anzeigenmodule | 10 (Auslegung bis 32) |
| Modultyp | Palettenmodulreihe A, Modulgröße 1, 40 Blatt |
| Zeichenvorrat | 38 Zeichen + Leerbild, siehe Anhang A |
| Vollständiges Display-Update | ≤ 2,4 s (eine volle Umdrehung) |

---

## 3. Bestandsanalyse: Anzeigenmodul

### 3.1 Mechanik und Positionserfassung

Der Blattsatz wird von einem Synchronmotor über ein Untersetzungsgetriebe angetrieben. Eine volle Umdrehung des Blattsatzes entspricht einer Umdrehung des großen Zahnrades (1:1). Übersetzung Motor zu großem Zahnrad bei 40 Blatt: 15 Zähne Ritzel zu 150 Zähnen, also 10:1.

Auf dem Impulsrad sitzen vier Zählimpuls-Magnete und ein Leerbild-Magnet, abgetastet von zwei Hall-Sensoren.

| Größe | Wert | Herleitung |
|---|---|---|
| Zählimpulse je Motorumdrehung | 4 | 4 Magnete |
| Motorumdrehungen je Blattsatzumdrehung | 10 | Übersetzung 10:1 |
| Zählimpulse je Blattsatzumdrehung | 40 | 10 × 4 |
| **Zählimpulse je Blatt** | **exakt 1** | 40 Impulse / 40 Blatt |
| Leerbildimpulse je Blattsatzumdrehung | 1 | Steuernocken am großen Zahnrad |
| Motordrehzahl | 250 U/min bei 50 Hz | Typenschild |
| Zykluszeit je Blatt | 60 ms | = 3 Netzperioden bei 50 Hz |
| Volle Umdrehung | 2,40 s | 40 × 60 ms |
| Mittlere Positionierzeit | 1,20 s | halbe Umdrehung |

Das System ist netzfrequenzstarr: 60 ms entsprechen exakt drei Netzperioden. Positionierzeiten sind damit deterministisch und lassen sich als Plausibilitätsprüfung nutzen.

### 3.2 Identifizierte Bauteile

| Bauteil | Typ | Anmerkung |
|---|---|---|
| Leiterplatte | KRONE 6281 3 160-00 K1/2, Code W | einseitig, Messpunkte MP1…MP8 beschriftet |
| Motor | Berger RSM 42/12, 42 V, 50/60 Hz, 250/300 U/min, 1,8 VA | Baujahr 10.90 |
| Triac | Teccor L201E3, TO-92 | 200 V, 1 A, sensitives Gate ca. 3 mA in allen vier Quadranten, V_GT max. 1,3 V |
| Treiberstufe | MPSA42 (NPN, 300 V) + MPSA92 (PNP, 300 V) | komplementäres Paar, Gate-Treiber |
| Überspannungsschutz | Siemens SIOV S14K60 | Varistor, 60 V~ Dauerbetrieb, Klemmung ca. 100 V |
| Motorkondensator | 2,2 µF / 100 V | Betriebskondensator, zieht ca. 29 mA Blindstrom |
| Hall-Sensoren | Beschriftung „03F 936" | 2 Stück, verdeckt unter dem Impulsrad, Open Collector ⚠️ |
| Filterkondensatoren | WIMA 0,047 µF und 0,1 µF, 63 V | im Treiberzweig |

### 3.3 Elektrische Daten (aus Originaldokumentation)

| Größe | Wert |
|---|---|
| Logikversorgung | +5 V ±5 %, ca. 0,8 mA |
| Hall-Sensoren | +5 V…+6 V, typ. 15 mA |
| Triac-Steuerspannung | +12 V…+20 V, 6,4…1,7 mA |
| Motor | 42 V~ +10 % / −15 % → **35,7 … 46,2 V**, Mod. 1 und 2 typ. 100 mA |
| Temperaturbereich | −20 °C bis +60 °C |
| rel. Feuchte | bis 95 % bei +40 °C, ohne Kondensation |
| MTBF | 1,5 · 10⁶ Rotorumdrehungen |

### 3.4 Anschlussbelegung 10-poliger Stecker

Bauform: Pfostenstecker 2×5, Raster 2,54 mm. Auf der Lötseite sind die geraden Pins (2, 4, 6, 8, 10) in einer Reihe beschriftet, die ungeraden liegen in der zweiten Reihe.

| Pin | Signal | Status |
|---|---|---|
| 1 | Masse | ✅ Originaldoku |
| 2 | 42 V~ | ✅ Originaldoku |
| 3 | Masse, mit Pin 1 verbunden | ✅ Originaldoku |
| 4 | 42 V~ | ✅ Originaldoku |
| 5 | Versorgung, mit Pin 6 verbunden | ✅ Originaldoku |
| 6 | Versorgung +5…+6,6 V | ✅ Originaldoku |
| 7 | Nullimpuls, Funktion unbekannt | ⚠️ wird nicht ausgewertet |
| 8 | Leerbild-Impuls, Ruhepegel high, Impuls zieht nach Masse | ✅ Originaldoku |
| 9 | Triac-Schalteingang | ✅ Originaldoku |
| 10 | Blatt-Impuls (Zählimpuls), Ruhepegel high, Impuls zieht nach Masse | ✅ Originaldoku |

**Es gibt keine getrennten Potenzialbereiche.** Masse und Versorgung liegen jeweils doppelt auf dem Stecker, sind aber untereinander verbunden. Die Doppelbelegung dient der Stromtragfähigkeit, nicht der Trennung.

Eine frühere Widerstandsmessung am abgezogenen Stecker hatte Pin 1 gegen Pin 3 und Pin 5 gegen Pin 6 als getrennt ausgewiesen. Das ist kein Widerspruch: Die Verbindung wird auf der Seite der Palettensteuerung hergestellt, nicht auf der Anzeigenplatine. Da die originale PST die Pins gebrückt hat, ist das Brücken auf der Daughter Card durch den Originalbetrieb belegt und unbedenklich.

**Die 42 V~ an Pin 2 und Pin 4 sind gegenüber der Logikmasse potenzialfrei.** Die Trafowicklung darf nicht mit der Masse verbunden werden. Der Gate-Kreis des Triacs ist auf MT1 bezogen und schwimmt damit auf dem Wechselspannungspotenzial. Genau das erklärt die 300-V-Typen MPSA42 und MPSA92 auf der Anzeigenplatine: Sie bilden die Pegelverschiebung zwischen dem massebezogenen Steuereingang an Pin 9 und dem potenzialfreien Gate-Kreis.

### 3.5 Blattbelegung

Siehe Anhang A. Kurzform: Blatt 1 und 2 sind Leerbilder, Blatt 3–12 tragen die Ziffern 0–9, Blatt 13–38 die Buchstaben A–Z, Blatt 39 den Bindestrich, Blatt 40 den Punkt.

---

## 4. Modulsteuerung (Daughter Card)

### 4.1 Auswahl der CPU

**Gewählt: Microchip ATtiny1616, SOIC-20**

| Kriterium | Begründung |
|---|---|
| Versorgung 5 V | identisches Potenzial wie Hall-Sensoren, keine Pegelwandler nötig |
| USART mit RS-485-Modus | XDIR-Pin steuert den Bustreiber hardwareseitig byte-genau |
| 16 KB Flash, 2 KB RAM | reichlich für den Anwendungsumfang |
| 256 B EEPROM | Adresse, Blattzahl, Offset, Abschaltvorhalt ohne Neuflashen änderbar |
| 20 MHz interner Oszillator, werkskalibriert | kein Quarz erforderlich |
| UPDI-Programmierung | eine Leitung, Adapter aus FTDI-Wandler und 4,7 kΩ |
| −40 °C bis +105 °C | deckt −20…+60 °C mit Reserve |
| Preis ca. 1,50 € | angemessen bei 10 Stück |

Verworfene Alternativen: CH32V003 (3,3 V, Pegelwandlung nötig, Vorteil erst ab großen Stückzahlen), ESP32-C3 je Modul (Kosten, Stromaufnahme und Komplexität ohne Gegenwert bei fest verkabeltem Aufbau).

### 4.2 Pinbelegung

| Pin | Port | Funktion |
|---|---|---|
| 9 | PB2 | USART0 TXD → RS-485-Treiber DI |
| 8 | PB3 | USART0 RXD ← RS-485-Treiber RO |
| 11 | PB0 | USART0 XDIR → DE (byte-genaue Senderichtung) |
| 2 | PA4 | Blatt-Impuls, Flanken-Interrupt (PORTA) |
| 3 | PA5 | Leerbild-Impuls, Flanken-Interrupt (PORTA) |
| 4 | PA6 | Nullimpuls, nur Messpunkt, Firmware wertet nicht aus |
| 5 | PA7 | Triac-Ansteuerung → Transistorschalter auf Pin 9 |
| 17 | PA1 | CHAIN_IN |
| 18 | PA2 | CHAIN_OUT |
| 19 | PA3 | Status-LED |
| 6, 7 | PB5, PB4 | Reserve, herausgeführt auf Testpad TP1 bzw. TP2 |
| 10, 12–15 | PB1, PC0…PC3 | Reserve, im Schaltplan unbeschaltet (kein Pad). PB1 ist USART0 XCK, im Async-Betrieb ungenutzt. Siehe `docs/pruefpunkte-t4.md` P-1 und `docs/pruefpunkte-t7.md` P-3. |
| 16 | PA0 | UPDI |
| 1, 20 | VDD, GND | Versorgung |

USART0 liegt auf der Standard-MUX-Position (`PORTMUX.USART0 = DEFAULT`).
Die alternative Position (PA1…PA4) ist durch CHAIN, Status-LED und den
Blattimpuls belegt. Belegt über `pruefpunkte-t7.md` P-3.

**Hinweis zur Beschaltung des Bustreibers:** XDIR steuert ausschließlich DE. Der Empfängerfreigabeeingang /RE wird fest auf GND gelegt, der Empfänger ist also dauerhaft aktiv. Die Karte liest damit ihre eigene Sendung zurück. Die Firmware verwirft dieses Echo im Normalbetrieb und nutzt es zur Kollisionserkennung, siehe 4.5.

### 4.3 Signalanpassung Impulseingänge

Je Eingang (Blatt an Pin 10, Leerbild an Pin 8, Nullimpuls an Pin 7):

- Pull-up 10 kΩ nach +5 V (Hall-Sensoren mit Open-Collector-Ausgang)
- Serienwiderstand 1 kΩ
- Kondensator 10 nF nach GND (Grenzfrequenz ca. 16 kHz, τ = 10 µs)
- Klemmdioden BAT54S gegen +5 V und GND

**Auswertende Flanke: fallend.** Der Ruhepegel ist high, der Impuls zieht die Leitung nach Masse. Die Firmware wertet ausschließlich die fallende Flanke aus.

Die Eingänge des ATtiny sind Schmitt-Trigger-Eingänge, ein zusätzlicher Trigger-Baustein entfällt.

Softwareseitige Entprellung: Der Mindestabstand zweier Blattimpulse beträgt 60 ms. Jede Flanke innerhalb von 20 ms nach der vorhergehenden wird verworfen.

### 4.4 Triac-Ansteuerung

Der Triac (L201E3) sitzt mit seiner Treiberstufe auf der Anzeigenplatine. Die Daughter Card bedient ausschließlich den Steuereingang an **Pin 9**, der auf die gemeinsame Masse bezogen ist.

**Optokoppler und isolierter DC/DC-Wandler entfallen.** Sie waren nur nötig, solange von einer getrennten Triac-Domäne ausgegangen wurde. Da Masse und Versorgung durchgehend gemeinsam sind, genügt ein einfacher Transistorschalter. Das spart je Karte rund 1,50 € und eine Bauteilkategorie.

**Offen bleibt die Ansteuerpolarität und der Pegel.** Die Originaldokumentation nennt für den Triac-Steuerkreis 12 bis 20 V bei 6,4 bis 1,7 mA. Der Stecker führt aber keine eigene 12–20-V-Versorgung, sondern nur die 5-V-Schiene an Pin 5 und 6. Zwei Deutungen sind möglich:

- **Deutung 1:** Pin 9 erwartet einen Strom aus einer 12–20-V-Quelle. Dann muss die Daughter Card diese Spannung bereitstellen.
- **Deutung 2:** Die Anzeigenplatine erzeugt die 12–20 V selbst aus den 42 V~, und Pin 9 ist ein logikpegelfähiger Eingang.

Die Angabe der Originaldoku ist in sich unstimmig, da der Strom mit steigender Spannung fällt. Das lässt sich mit einem einfachen Vorwiderstand nicht erklären und spricht für eine aktive Stufe hinter Pin 9. Klärung über O-2.

**Ausgeführte Schaltung, deckt beide Deutungen ab:**

```
                    ┌─── Lötjumper JP1 ──── +5 V
   VDRV ────────────┤
                    └─── Lötjumper JP2 ──── +15 V (Buskabel Ader 9)

                       VDRV
                         │
                        [R_S]        Quelle (Vorgabe)
                         │
   PA7 ──[10k]── BSS84 ──┴────────── Pin 9
              (P-Kanal, High-Side)

   PA7 ──[10k]── MMBT3904 ────────── Pin 9        Senke (Alternative)
                    │
                   GND
```

Bestückt wird jeweils nur ein Zweig. Vorgabe ist die Quelle mit R_S = 4,7 kΩ und VDRV = 15 V, was rund 3 mA ergibt und damit im Zündbereich des L201E3 liegt. Zeigt die Messung, dass 5 V genügen, wird JP1 gesetzt und R_S auf 1,2 kΩ reduziert.

In beiden Zweigen gilt laut Netzliste (`docs/schaltplan-daughtercard.md` 5.4/Kap. 6): **PA7 high = Motor an.** Eine Invertierung in der Firmware ist daher nicht vorgesehen; das früher dafür reservierte Flag-Bit 2 ist entfallen (v0.29, Issue #18) – ein gesetztes Bit 2 hätte den Motor in IDLE/ERROR dauerhaft bestromt.

**Rückfallebene:** Der L201E3 zündet mit rund 3 mA in allen vier Quadranten. Sollte sich die Originalstufe als unbrauchbar erweisen, kann das Gate direkt über einen Optotriac-Treiber (MOC3052 oder MOC3063) bedient werden. Das erfordert einen Eingriff auf der Anzeigenplatine und ist nicht der bevorzugte Weg.
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

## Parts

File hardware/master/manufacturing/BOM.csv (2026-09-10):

Comment | Designator | Footprint | LCSC Part #
100R | R5 | R_0805_2012Metric | C17408
100k | R8 | R_0805_2012Metric | C149504
100n | C1 C2 C4 | C_0805_2012Metric | C49678
10k | R4 | R_0805_2012Metric | C17414
10u | C5 | C_0805_2012Metric | C15850
120R | R1 | R_0805_2012Metric | C17437
1k | R6 | R_0805_2012Metric | C17513
47u | C3 | C_1206_3216Metric | C76659
60R@100MHz | FB1 | L_0805_2012Metric | C18305
680R | R2 R3 | R_0805_2012Metric | C17798
74LVC1G17 | U3 | SOT-23-5 | C19829593
AO3401A | Q1 | SOT-23 | C15127
SM712 | D2 | SOT-23 | C32677
TP8485E-SR | U2 | SOIC-8_3.9x4.9mm_P1.27mm | C94206
gruen | D1 | LED_0805_2012Metric | C2297

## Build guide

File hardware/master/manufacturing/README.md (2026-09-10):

# Fertigungspaket Zentralsteuerung (Master)

Erzeugt von `tools/gen_master_manufacturing.py` aus der committeten
`master.kicad_pcb`. Bei jeder Layoutaenderung neu erzeugen.

| Datei | Zweck |
|---|---|
| `master-gerbers.zip` | Gerber + Excellon-Bohrdatei, komplett. Bei JLCPCB hochladen. |
| `gerber/` | dieselben Dateien einzeln (Kontrolle im Gerber-Viewer) |
| `BOM.csv` | Bestueckliste fuer den SMT-Dienst (JLCPCB-Format) |
| `CPL.csv` | Bestueckungsplan / Pick&Place (JLCPCB-Format) |

## Platine

- 68 x 54 mm, 2 Lagen, 1,6 mm FR4, 35 um Kupfer.
- **Loetstoppmaske schwarz, Bestueckungsdruck weiss** (im Lagenaufbau gesetzt;
  bei JLCPCB die Option "Black solder mask, White silkscreen" waehlen).
- Oberflaeche: HASL bleifrei genuegt.
- Maker-Kennzeichnung (GitHub-Marke + "TenOfNine") auf der Rueckseiten-Silkscreen.
- **Antennenbereich unter U1** (Unterkante des Moduls): Massefläche ist dort
  ausgespart (Footprint-Keepout). Wenn moeglich das Modul so einbauen, dass
  die Antenne ueber die Platinenkante ragt.

## Bestueckung

`BOM.csv` / `CPL.csv` enthalten **18 SMD-Bauteile** (alle Oberseite,
0805 / SOIC-8 / SOT-23 / SOT-23-5), alle als LCSC-Basic-Teile. Der Master
ist ein Einzelstueck -- die komplette Handbestueckung ist zumutbar;
JLCPCB-SMT ist optional.

**Immer von Hand** zu bestuecken (nicht im SMT-Auftrag):

| Ref | Teil |
|---|---|
| J1 | Schraubklemme 2-polig, RM 5,08 mm (+5V IN) |
| J2 | Wannenstecker 2x5, 2,54 mm, gerade (Bus zur ersten Daughter Card) |
| J3 | Stiftleiste 1x4, 2,54 mm (Reserve GPIO0/1/7 + GND) |
| J4 | Aufwaertswandler-Modul 5 V -> 15 V (nur falls O-2 Deutung 1), DNP |
| JP1 | Loetbruecke 3-Wege: Ader 9 = offen / +5V / +15V |
| U1 | ESP32-C3 Super Mini, gesteckt in 2x 1x8 Buchsenleisten 2,54 mm |

> Die `CPL.csv`-Drehungen kommen unveraendert aus KiCad. JLCPCB rechnet
> fuer SOT-23 / SOIC / LED eine eigene Referenzdrehung an -- im
> JLC-Vorschaufenster **U2, U3, Q1, D1 und D2 einzeln auf Pin 1 /
> Polaritaet pruefen** (D2 = SM712: Pin 3 = GND).

## Bauteil-Hinweise

- **U1 ESP32-C3 Super Mini:** Aftermarket-Modul, Pinbelegung + Einbaulage in
  `docs/symbolpruefung-master.md`. USB-C/BOOT/RST an der Oberkante, Antenne
  (Aufdruck "ESP32-C3 Super Mini") an der Unterkante. 5V-Pin = rechts oben.
- **U3 74LVC1G17** hebt CHAIN von 3,3 V auf 5 V. Zeigt der Test, dass 3,3 V
  direkt genuegen (M-3), wird U3 weggelassen und **R7 (0 Ohm)** bestueckt.
- **J4 / Step-up** bleibt unbestueckt, bis O-2 zeigt, dass die Anzeige an
  Pin 9 mehr als 5 V braucht. Dann Modul auf 15,0 V einstellen, JP1 auf +15V.
- **JP1** bei Auslieferung offen (Ader 9 unbeschaltet).

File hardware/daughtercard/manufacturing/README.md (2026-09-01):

# Fertigungspaket Daughter Card

Erzeugt von `tools/gen_manufacturing.py` aus der committeten
`daughtercard.kicad_pcb`. Bei jeder Layoutaenderung neu erzeugen.

| Datei | Zweck |
|---|---|
| `daughtercard-gerbers.zip` | Gerber + Excellon-Bohrdatei, komplett. Bei JLCPCB hochladen. |
| `gerber/` | dieselben Dateien einzeln (Kontrolle im Gerber-Viewer) |
| `BOM.csv` | Bestueckliste fuer den SMT-Dienst (JLCPCB-Format) |
| `CPL.csv` | Bestueckungsplan / Pick&Place (JLCPCB-Format) |

## Platine

- 74 x 60 mm, 2 Lagen, 1,6 mm FR4, 35 um Kupfer.
- **Loetstoppmaske schwarz, Bestueckungsdruck weiss** (im Lagenaufbau gesetzt; bei JLCPCB die passende Option waehlen).
- Oberflaeche: HASL bleifrei genuegt.
- Maker-Kennzeichnung (GitHub-Marke + "TenOfNine") auf der Rueckseiten-Silkscreen.

## SMT-Bestueckung

`BOM.csv` / `CPL.csv` enthalten **30 SMD-Bauteile**, alle auf der
Oberseite. Nicht enthalten: DNP (Q3, R10), Loetjumper JP1-JP3, Testpunkte
TP1-TP7, Bohrungen -- und **die Steckverbinder J1-J6, die von Hand geloetet
werden**.

> Die `CPL.csv`-Drehungen kommen unveraendert aus KiCad. JLCPCB rechnet
> fuer manche Gehaeuse (SOT-23, SOIC, LED) eine eigene Referenzdrehung an.
> Im JLC-Vorschaufenster **jedes SOT-23 (Q1, Q2, D1-D3), U1, U2 und die
> LED D4 einzeln auf Polaritaet/Pin-1 pruefen** und die Drehung dort
> korrigieren, nicht in der CSV.

### Bauteil-Hinweise

- Alle Positionen haben eine LCSC-Nummer -- die Bestueckung bleibt im
  **Economic PCBA** (die gruene LED ist als 0805 `C2297` gesetzt, nicht 0201).
- **Extended** (je einmalig ~3 USD Ruestkosten, Economic-tauglich):
  U1 `C614136`, U2 `C94206`, Q1 `C8492` (BSS84), D1-D3 `C19726` (BAT54S).
- **U1 ATtiny1616-SN (`C614136`)**: JLC-Lager ist knapp (Groessenordnung
  einige Dutzend). Vor der Bestellung Bestand pruefen; ggf. selbst nachloeten
  (SOIC-20, 300 mil, gut handlötbar) und aus der BOM/CPL nehmen.

## Von Hand zu loeten (nicht im SMT-Auftrag)

| Ref | Wert | Footprint | Referenzteil |
|---|---|---|---|
| J1 | Anzeige | `PinSocket_2x05_P2.54mm_Vertical` | Buchsenleiste 2x5, 2,54 mm, gerade (BKL 10120960) |
| J2 | Bus in | `IDC-Header_2x05_P2.54mm_Vertical` | Wannenstecker 2x5, 2,54 mm, gerade |
| J3 | Bus out | `IDC-Header_2x05_P2.54mm_Vertical` | Wannenstecker 2x5, 2,54 mm, gerade |
| J4 | 42V~ in | `TerminalBlock_Phoenix_MKDS-1,5-2-5.08_1x02_P5.08mm_Horizontal` | Schraubklemme 2-polig, RM 5,08 mm |
| J5 | 42V~ out | `TerminalBlock_Phoenix_MKDS-1,5-2-5.08_1x02_P5.08mm_Horizontal` | Schraubklemme 2-polig, RM 5,08 mm |
| J6 | UPDI | `PinHeader_1x03_P2.54mm_Vertical` | Stiftleiste 1x3, 2,54 mm |

> ⚠️ **J1 ist nicht kodiert** und fuehrt an Pin 2/4 die 42 V~. Vor dem
> ersten Einschalten die Drehlage und den Durchgang gegen die
> Anzeigenplatine pruefen -- siehe `docs/pruefpunkte-j1-buchsenleiste.md`
> und Schaltplan Kapitel 4.1 / Pruefliste 9.

## Netzklassen im Layout

Alle Leiterbahnen 0,5 mm (an SOIC-Pins auf 0,375 mm verjuengt), nur
AC1/AC2 = 1,5 mm. GND ueber die Masseflaeche auf beiden Lagen. Zum
Spannungsabfall der +5V-Kette bei 0,5 mm siehe `docs/jlc-bestueckung.md` D-5.

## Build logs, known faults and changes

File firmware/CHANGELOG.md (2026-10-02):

# Firmware-Änderungshistorie

Eine gemeinsame Versionsnummer für Master- (`firmware/master/`) und
Modul-Firmware (`firmware/module/`) — beide werden im Gleichschritt
entwickelt und ausgeliefert.

**Schema:** `MAJOR.MINOR`.

- **MINOR** steigt bei jeder ausgelieferten Änderung an einer der beiden
  Firmwares (Fix, neues Feature, Aufräumen).
- **MAJOR** steigt nur bei großen Änderungen — z. B. einem Bruch im
  Busprotokoll, einem grundlegenden Architekturwechsel, oder dem Übergang
  von der Inbetriebnahme-Phase zum dauerhaften Betrieb mit allen zehn
  Anzeigenmodulen. Bisher noch nicht eingetreten — die gesamte Historie
  unten ist `1.x`.

**Wo die Version steckt:**

- Master: `FW_VERSION_MAJOR`/`FW_VERSION_MINOR` in `firmware/master/src/main.cpp`,
  ausgeliefert über `/api/system` (`fw_version`) und in der Web-UI-Fußzeile.
- Modul: `APP_VERSION_MAJOR`/`APP_VERSION_MINOR` in `firmware/module/src/board.h`,
  ausgeliefert über `CMD_GET_VERSION` — die Web-UI zeigt sie im Panel
  „Modul-Firmware" je Karte an, sobald die Version abgefragt wurde.

**Pflicht bei jeder Firmware-Änderung:** Zeile unten anhängen und die
beiden `*VERSION_MINOR`-Konstanten hochzählen, alle Prebuilts neu erzeugen und
danach mit `python tools/make_release.py` das Release-Tag `vMAJOR.MINOR`
anlegen und pushen – daraus entsteht das GitHub-Release, das der Webflasher
zur Auswahl anbietet (siehe CLAUDE.md Arbeitsweise).

## Historie

| Version | Commits | Änderung |
|---|---|---|
| 1.0 | `f01190b`, `175b709`, `8ad7f10`, `07cd236` | Grundarchitektur: hardwareunabhängige Protokoll-/Enumerationsbibliothek (host-getestet), Modul-Firmware ATtiny1616 bare metal, Master-Firmware ESP32, erste Repo-Review-Fixes (Sendeecho-Bug, IDENTIFY) |
| 1.1 | `23a0a93` | Master auf ESP32-C3 Super Mini portiert (UART1, GPIO-Pins, natives USB) |
| 1.2 | `fe3a97b`, `4261649` | Eventlog, Bus-Zähler, erweiterte Status-JSON; neue Web-Oberfläche (Dark-Theme, Log-Tab, Einstellungen) |
| 1.3 | `4bd3a7e`, `5b0a262` | Hostname editierbar, Systemdiagnose, Voll-Backup; Zeitzonen-Auswahlliste + Sommerzeit-Schalter |
| 1.4 | `e682f31`, `2a96a88`, `0ec7cbc`, `5dc4db5`, `c1488d7` | Browser-OTA, ArduinoOTA entfernt, `.kota`-Signaturprüfung, Zugriffsschutz (Herkunft + Basic-Auth), Betreiberschlüssel |
| 1.5 | `1d01cf6`, `b232303` | `charmap_char()` (Blattnummer → Zeichen); MQTT Last-Will/`availability_topic`, Discovery-Cleanup |
| 1.6 | `4c6c2b2`, `e847da6`, `60b721a`, `346e7a1` | Firmware-Verteilung an Module über den Bus (Bootloader, `lib/fwupdate`, Panel „Modul-Firmware"); automatische Modulzahl |
| 1.7 | `dc7bddc`, `c6ac2cd`, `01dcdd0`, `206afd8` | Web-UI-Fix (Syntaxfehler), Modul-Konfiguration über die UI, Einstellungen thematisch gruppiert, Projekt-Logo |
| 1.8 | `f24b861`, `bfe736c`, `57ed779`, `892c67f`, `7a32284`, `a2965e4`, `67dc876`, `2a55e10`, `3cda3a6`, `cd244dd`, `3374dc0`, `8aa33e7`, `1dd87dc` | Master-PCB-Inbetriebnahme: DI-Pin-Bug im Modul gefunden+behoben, LED-Blinkraten/-Helligkeit korrigiert, Bus-Debug-Einstellung + Live-Log in der Web-UI, Versionsabfrage-Fix, Issue #16 (Mehrkarten-Instabilität: Root Cause + Fix) |
| 1.9 | `3ee3d9f`, `3d65464` | Firmware-Versionsnummer eingeführt (dieses Schema); Bootloader hatte denselben DI-Pin-Bug wie die App (eigene, unabhängige USART0-Initialisierung) — erster realer Test der Firmware-Verteilung über den Bus deckte es auf, beide Karten blieben im Bootloader hängen, Browser-Werksflash nötig zur Wiederherstellung |
| 1.10 | `943d796` | Master: Firmware-Update direkt aus dem GitHub-Repository (`POST /api/update/github`, lädt das neueste committete `.kota` über HTTPS, gleiche Signatur-/Hash-Prüfung wie der Browser-Upload). Braucht Internetzugriff der Steuerung selbst. Modul-Version mitgezogen (kein Funktionsunterschied, nur Versionsgleichstand) |
| 1.11 | `afe15e8` | Mobile Web-UI: Marke/Titel blieb beim horizontalen Scrollen der Navigationsleiste unter 820 px Breite nicht sichtbar (`.side` scrollte als ein Block samt `.brand`) — Marke jetzt fest, nur die Tab-Leiste scrollt. Modul-Version mitgezogen (kein Funktionsunterschied, nur Versionsgleichstand) |
| 1.12 | `d73b2dd` | Fix: `g_bus.mod[].ver_known` wurde nach der ersten erfolgreichen `CMD_GET_VERSION`-Antwort nie wieder zurückgesetzt — der reguläre Versions-Poll fragt ein "bekanntes" Modul nie erneut ab, daher zeigte die UI nach einem erfolgreichen Bus-Update weiter die alte Version an, obwohl `lib/moduleupdate` die neue Version bereits selbst per `GET_VERSION` bestätigt hatte. `ver_known` wird jetzt zurückgesetzt, sobald `moduleupdate` eine Adresse abschließt (Erfolg oder Fehlschlag), sodass der reguläre Poll sie neu lernt. Modul-Version mitgezogen (kein Funktionsunterschied, nur Versionsgleichstand). |
| 1.13 | `3a72acf` | Synchrones LED-Blinken: neuer Broadcast `CMD_LED_SYNC` (0x41, `lib/protocol`), den der Master alle ~1 s sendet (`busmaster_led_sync()`); Module (und der Master selbst über `g_bus.led_sync_ms`) nullen darauf ihre Blinkphase, statt seit dem jeweils eigenen Boot-Zeitpunkt zu zählen — alle Status-LEDs blinken jetzt im gleichen Takt. |
| 1.14 | `15d4065` | Fix: Eine Karte, die mitten in `FW_DATA`/`FW_END` hängen bleibt (App bereits ungültig markiert, Bootloader wartet korrekt auf neues `FW_BEGIN`), beantwortet `CMD_GET_STATUS` nicht mehr und gilt als offline — „Alle aktualisieren"/„Veraltete aktualisieren" filtern aber beide auf online, die Karte war über den Bus nie wieder erreichbar. Neuer Button „Offline erneut versuchen" + `handle_module_update()` lässt explizit angefragte Adressen immer zu, unabhängig vom Online-Status. Am Gerät gefunden (21.09.2026, Modul 2 nach abgebrochenem Update), Fix noch nicht am Gerät verifiziert. |
| 1.15 | `d9439a8` | Fix: Web-UI-Moduswahl „Text" sprang beim nächsten Status-Poll (alle 2,5 s) zurück auf den vorherigen Modus, bevor überhaupt etwas eingetippt werden konnte — der Klick auf „Text" sendet bewusst noch keinen `/api/mode` (erst „Senden"), der Poll glich die Anzeige aber sofort wieder an den unveränderten Server-Modus an. Neues `textPending`-Flag unterdrückt den Abgleich, solange die Texteingabe offen und unbestätigt ist. Modul-Version mitgezogen (kein Funktionsunterschied, nur Versionsgleichstand). |
| 1.16 | `6d49e5b`, `0d4e7d8`, `1736c89`, `39ed754`, `2e79c3e` | **Review-Fixes (zwei Voll-Reviews 30.09./01.10.2026, Issues #18–#43).** Modul: Flag-Bit 2 (Triac-Polarität) entfällt, Gate = Motorwunsch in allen Zuständen, gelöschte EEPROM-Abbilder werden auf Vorgaben migriert (#18); Plain-App setzt bei BOOTEND≠0 IVSEL, Watchdog nur bei laufender Zeitbasis, nach WDT-Reset Start in ERROR 0x05 (#19); SET_CONFIG sofort wirksam (#23); Positionsring ohne seq-Überlauf (#24); Zielpuffer, GO während Fahrt vorgemerkt (#25); Echo-Abweichung bricht ab, Rückfall nach T_enum, 0x06 im Status (#20/#28); EEPROM-Schreiben nicht blockierend. Bootloader BL 2: nie halbe App starten, Übertragung wiederaufsetzbar, Unicast/Längenprüfung, echtes 2,5-s-Fenster (#29/#30/#41, wirkt erst nach Werksflash). Master: Sendeende als Zeitbezug, Retry nur bei Busruhe, Sendewarteschlange (Ursache Positions-1-Adressverlust, #20/#21); robuste Enumeration, GET_UID-Verifikation, Warnung Serviceadresse 250 (#22/#28); Soll/Ist-Abgleich (#26); Betriebsart/Text dauerhaft (#27); Update-Sperre (#31); WLAN nicht blockierend, Portal ohne Firmware-Upload (#32/#35); Host-/CSRF-Prüfung (#33); XSS-Escaping (#34); mqtt_pass nicht mehr per GET (#38); JSON-Escaping/Puffer, Uptime, SNTP (#40). Am Gerät noch nicht verifiziert (#49). |

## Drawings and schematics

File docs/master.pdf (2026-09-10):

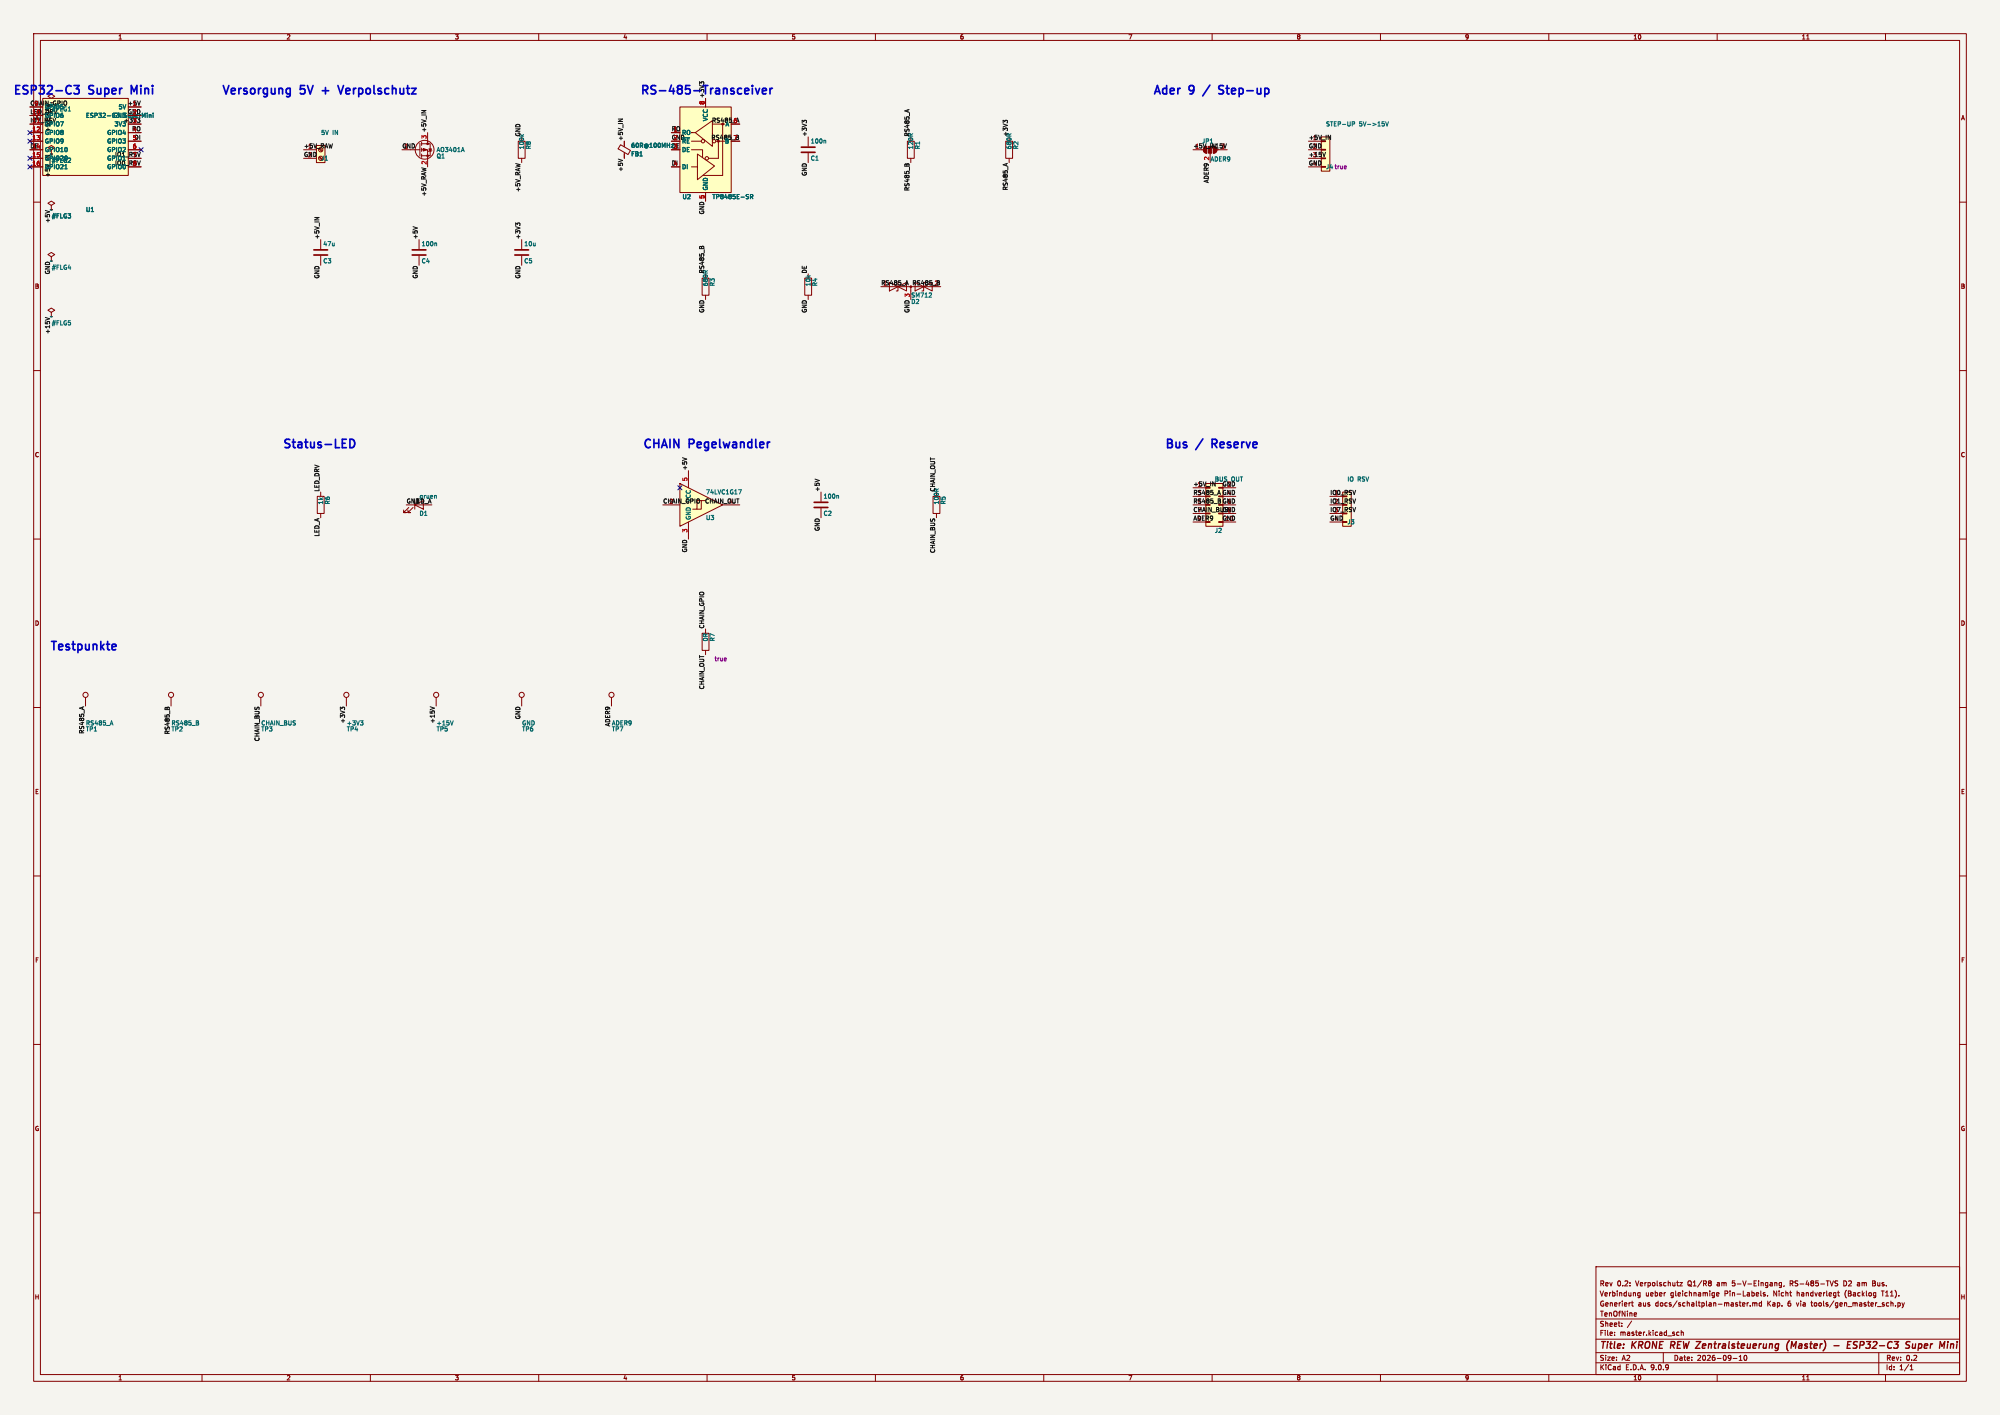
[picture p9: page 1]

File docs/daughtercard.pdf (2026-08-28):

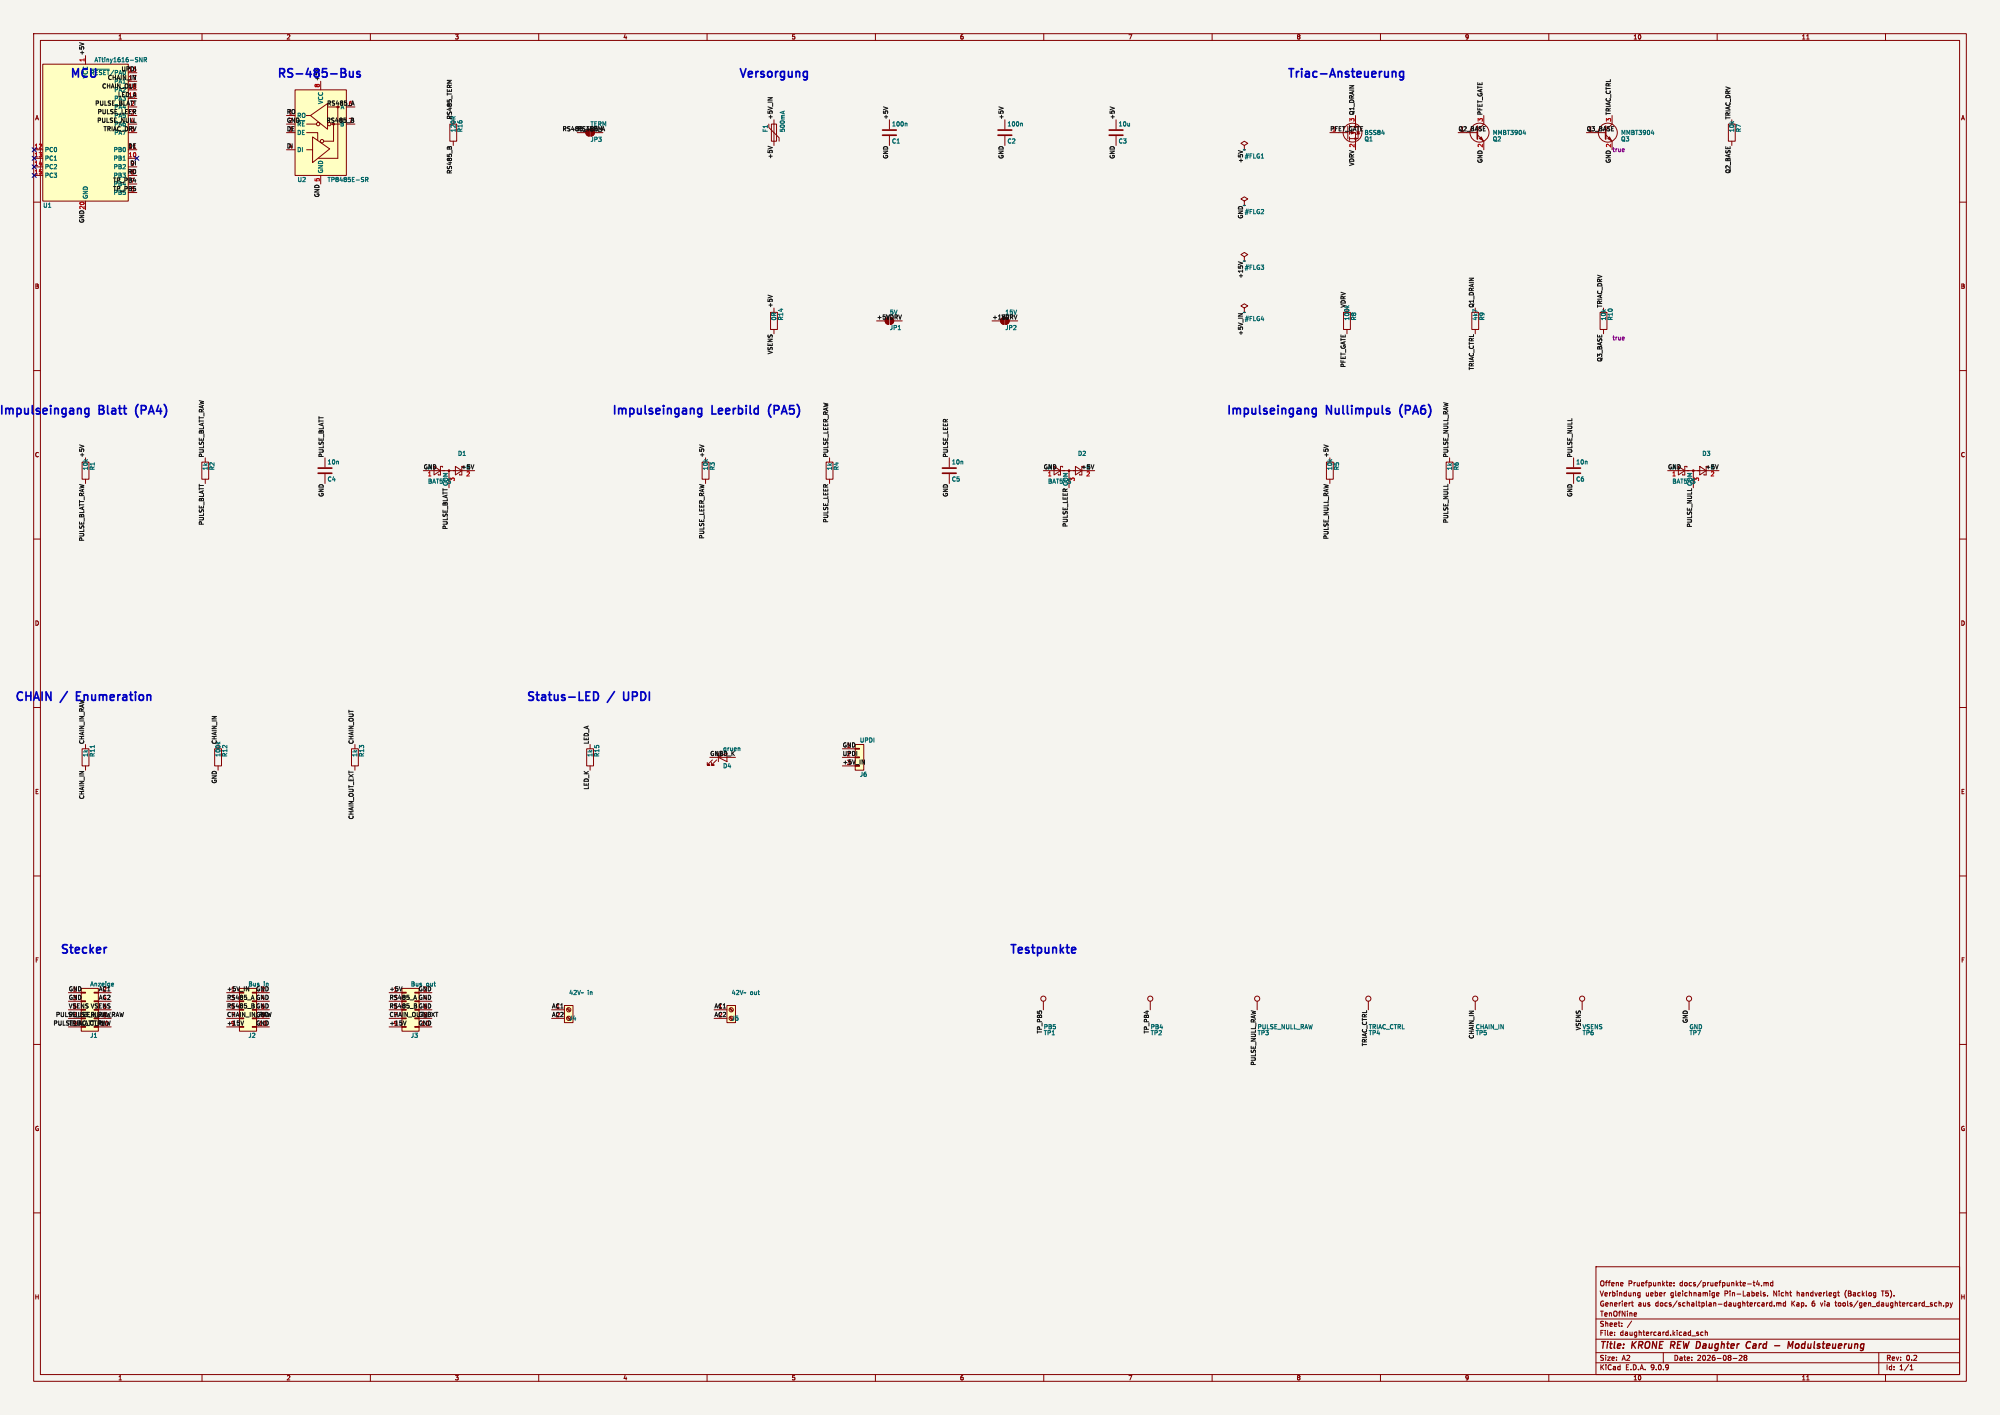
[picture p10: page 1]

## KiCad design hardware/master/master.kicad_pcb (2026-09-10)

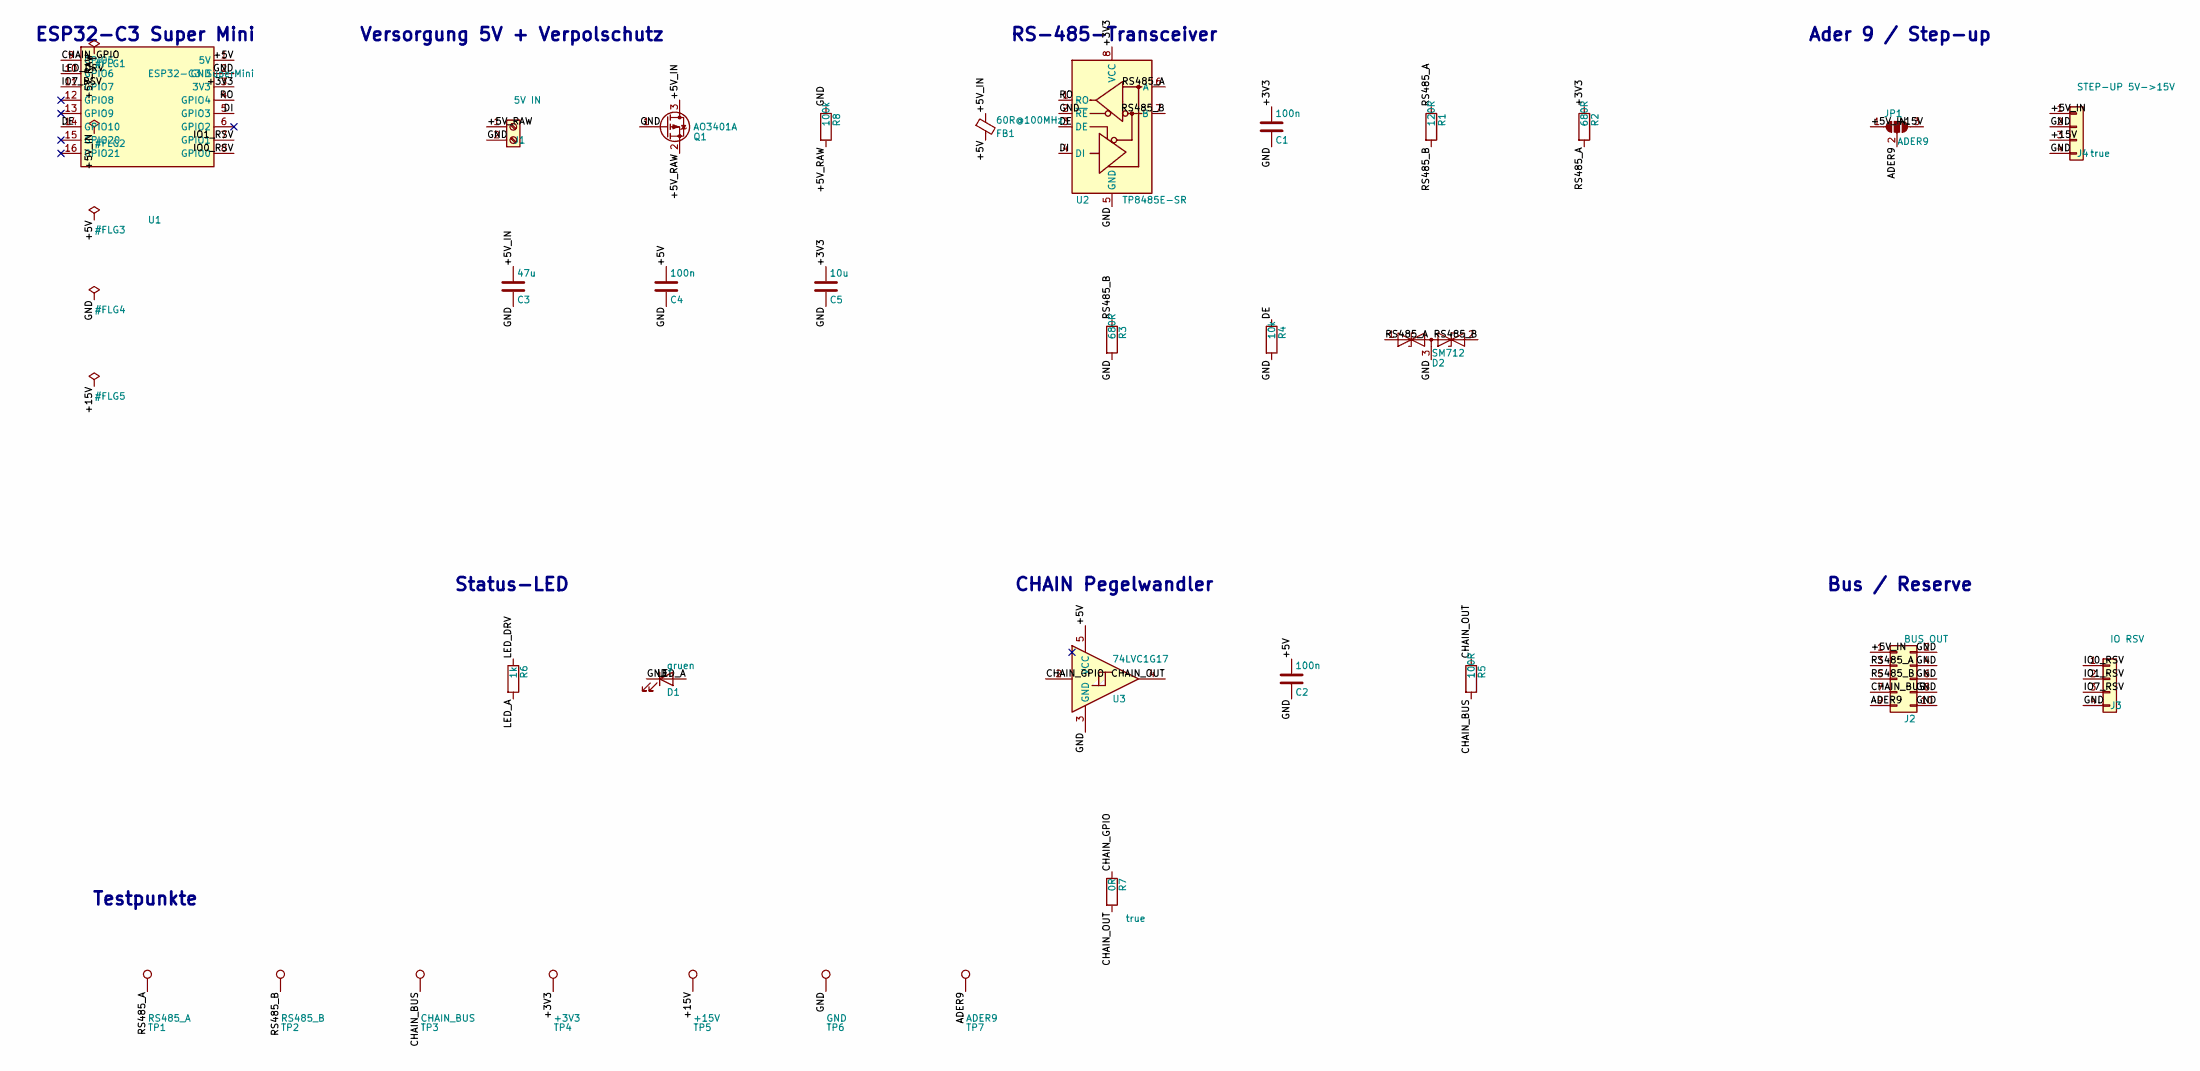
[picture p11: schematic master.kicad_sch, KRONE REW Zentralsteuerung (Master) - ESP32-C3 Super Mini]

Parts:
C1, C2, C4: 100n; C_0805_2012Metric
C3: 47u; C_1206_3216Metric
C5: 10u; C_0805_2012Metric
D1: gruen; LED_0805_2012Metric
D2: SM712; SOT-23
FB1: 60R@100MHz; L_0805_2012Metric
J1: 5V IN; TerminalBlock_Phoenix_MKDS-1,5-2-5.08_1x02_P5.08mm_Horizont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
J2: BUS OUT; IDC-Header_2x05_P2.54mm_Vertical
J3: IO RSV; PinHeader_1x04_P2.54mm_Vertical
J4: STEP-UP 5V->15V; PinHeader_1x04_P2.54mm_Vertical
JP1: ADER9; SolderJumper-3_P1.3mm_Open_Pad1.0x1.5mm
Q1: AO3401A; SOT-23
R1: 120R; R_0805_2012Metric
R2, R3: 680R; R_0805_2012Metric
R4: 10k; R_0805_2012Metric
R5: 100R; R_0805_2012Metric
R6: 1k; R_0805_2012Metric
R7: 0R; R_0805_2012Metric
R8: 100k; R_0805_2012Metric
TP1: RS485_A; TestPoint_Pad_D1.5mm
TP2: RS485_B; TestPoint_Pad_D1.5mm
TP3: CHAIN_BUS; TestPoint_Pad_D1.5mm
TP4: +3V3; TestPoint_Pad_D1.5mm
TP5: +15V; TestPoint_Pad_D1.5mm
TP6: GND; TestPoint_Pad_D1.5mm
TP7: ADER9; TestPoint_Pad_D1.5mm
U1: ESP32-C3 SuperMini; ESP32-C3-SuperMini
U2: TP8485E-SR; SOIC-8_3.9x4.9mm_P1.27mm
U3: 74LVC1G17; SOT-23-5

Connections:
/+3V3: C1.1, C5.1, R2.1, TP4.1, U1.3 (3V3), U2.8 (VCC)
/+5V: C2.1, C4.1, FB1.2, U1.1 (5V), U3.5 (VCC)
/+5V_IN: C3.1, FB1.1, J2.1, J4.1, JP1.1 (A), Q1.3 (D)
/+5V_RAW: J1.1, Q1.2 (S), R8.2
/+15V: J4.3, JP1.3 (B), TP5.1
/ADER9: J2.9, JP1.2 (C), TP7.1
/CHAIN_BUS: J2.7, R5.2, TP3.1
/CHAIN_GPIO: R7.1, U1.9 (GPIO5), U3.2
/CHAIN_OUT: R5.1, R7.2, U3.4
/DE: R4.1, U1.14 (GPIO10), U2.3 (DE)
/DI: U1.5 (GPIO3), U2.4 (DI)
/GND: C1.2, C2.2, C3.2, C4.2, C5.2, D1.1 (K), D2.3 (common), J1.2, J2.2, J2.4, J2.6, J2.8, J2.10, J3.4, J4.2, J4.4, Q1.1 (G), R3.2, R4.2, R8.1, TP6.1, U1.2 (GND), U2.2 (~RE), U2.5 (GND), U3.3 (GND)
/IO0_RSV: J3.1, U1.8 (GPIO0)
/IO1_RSV: J3.2, U1.7 (GPIO1)
/IO7_RSV: J3.3, U1.11 (GPIO7)
/LED_A: D1.2 (A), R6.2
/LED_DRV: R6.1, U1.10 (GPIO6)
/RO: U1.4 (GPIO4), U2.1 (RO)
/RS485_A: D2.1 (A1), J2.3, R1.1, R2.2, TP1.1, U2.6 (A)
/RS485_B: D2.2 (A2), J2.5, R1.2, R3.1, TP2.1, U2.7 (B)

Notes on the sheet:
ESP32-C3 Super Mini
Versorgung 5V + Verpolschutz
RS-485-Transceiver
CHAIN Pegelwandler
Status-LED
Ader 9 / Step-up
Bus / Reserve
Testpunkte

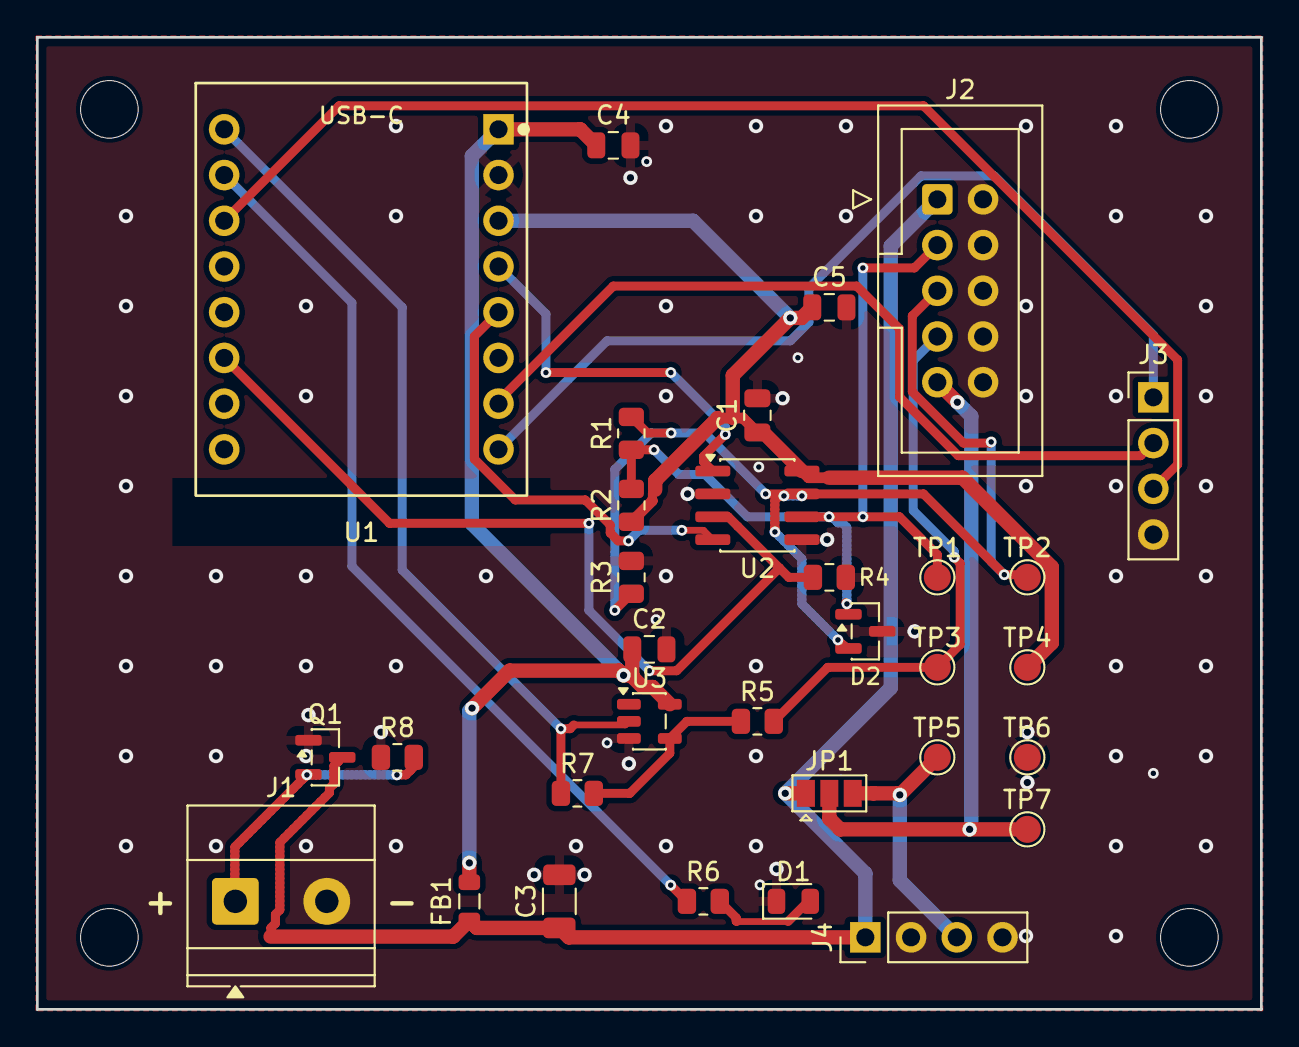
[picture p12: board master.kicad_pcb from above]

Board: 2 copper layers, 68.0 x 54.0 mm, 37 parts (1 on the bottom side), 20 nets.

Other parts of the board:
GH1: Logo_GitHub
H1, H2, H3, H4: MountingHole_3.2mm_M3

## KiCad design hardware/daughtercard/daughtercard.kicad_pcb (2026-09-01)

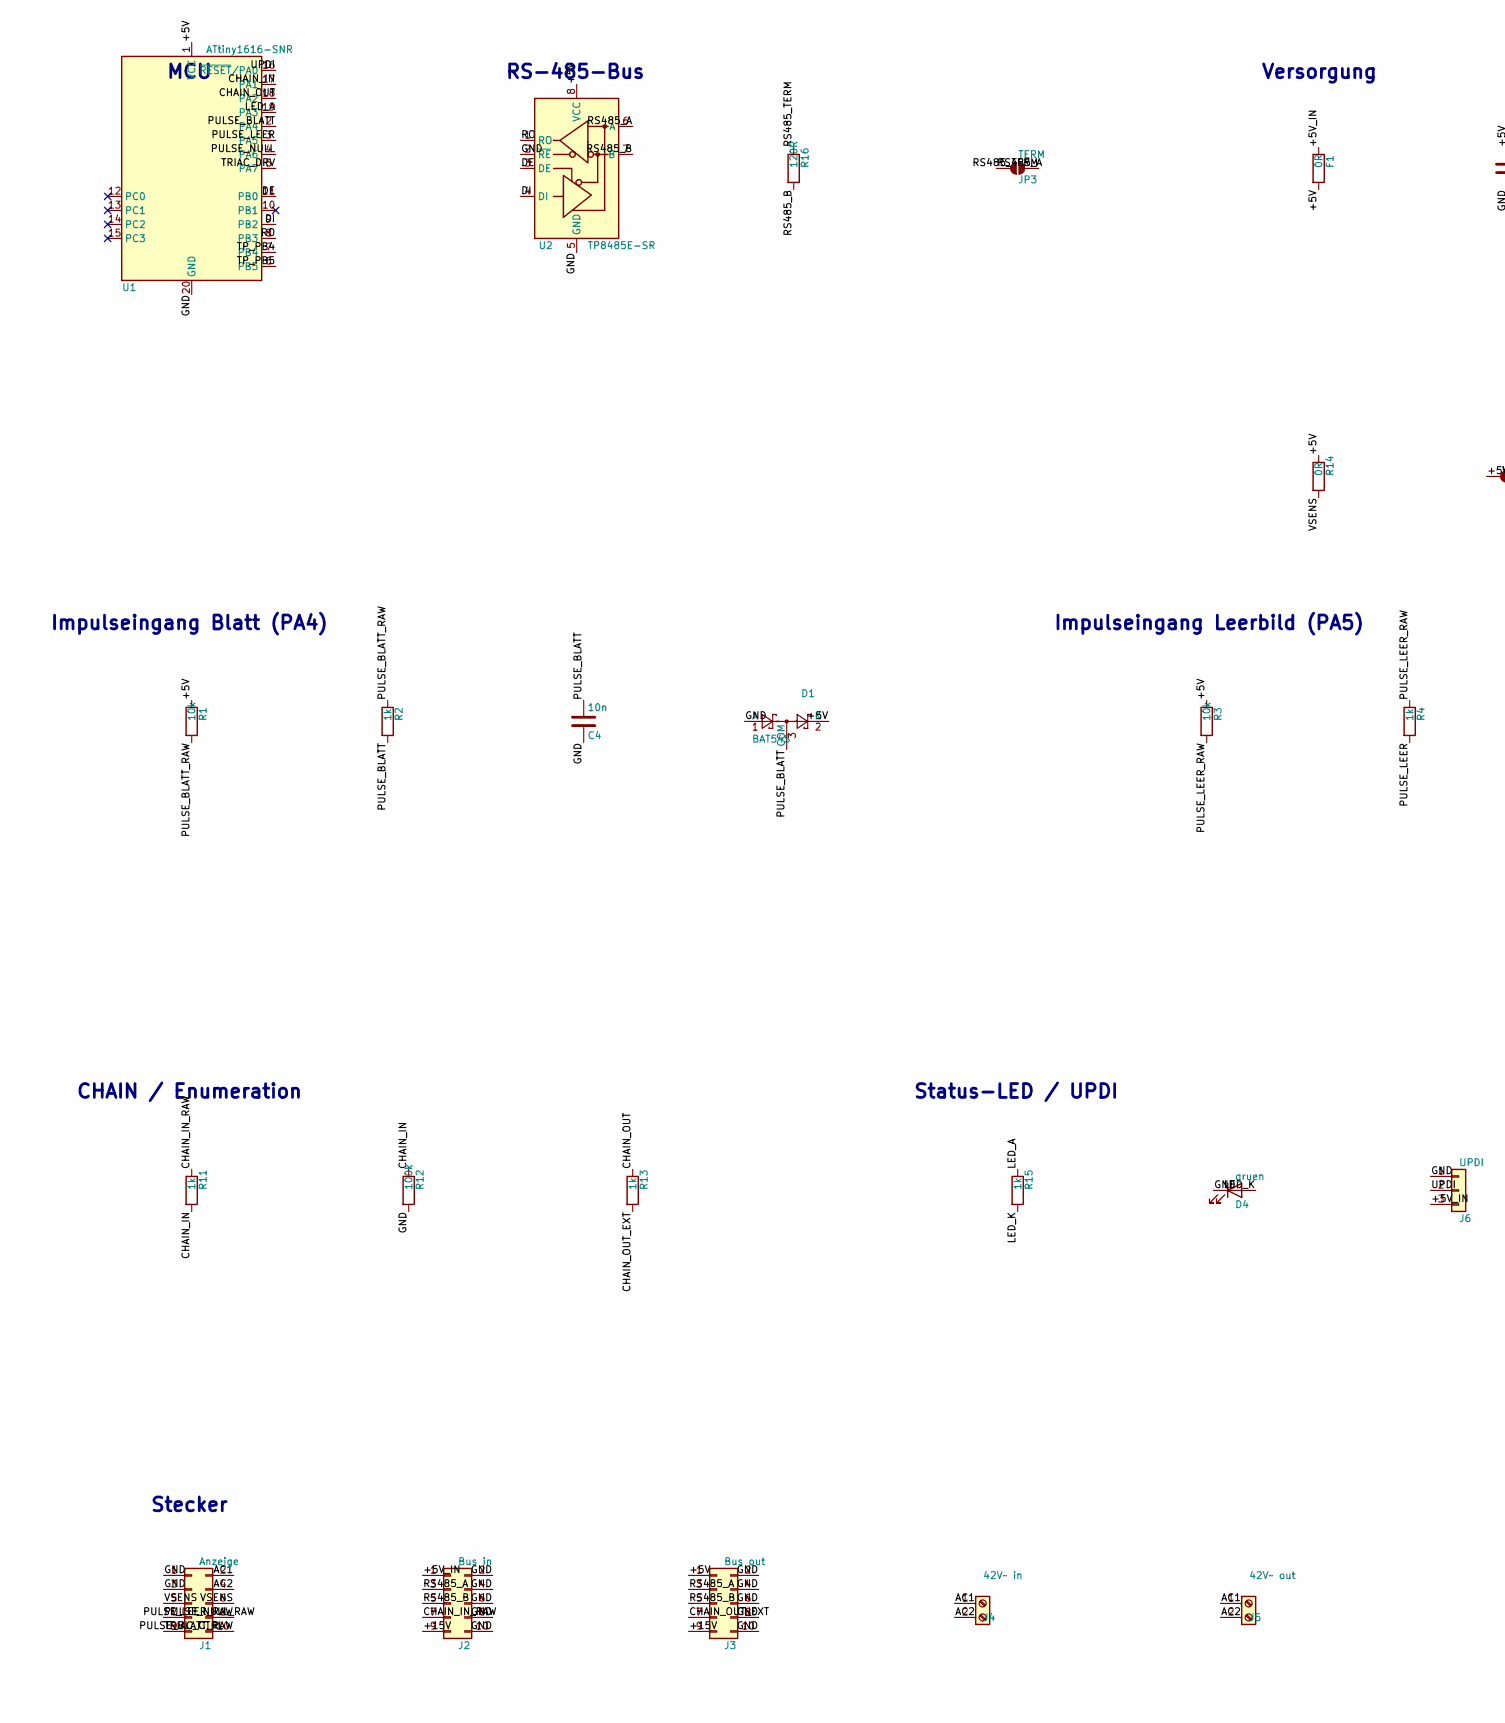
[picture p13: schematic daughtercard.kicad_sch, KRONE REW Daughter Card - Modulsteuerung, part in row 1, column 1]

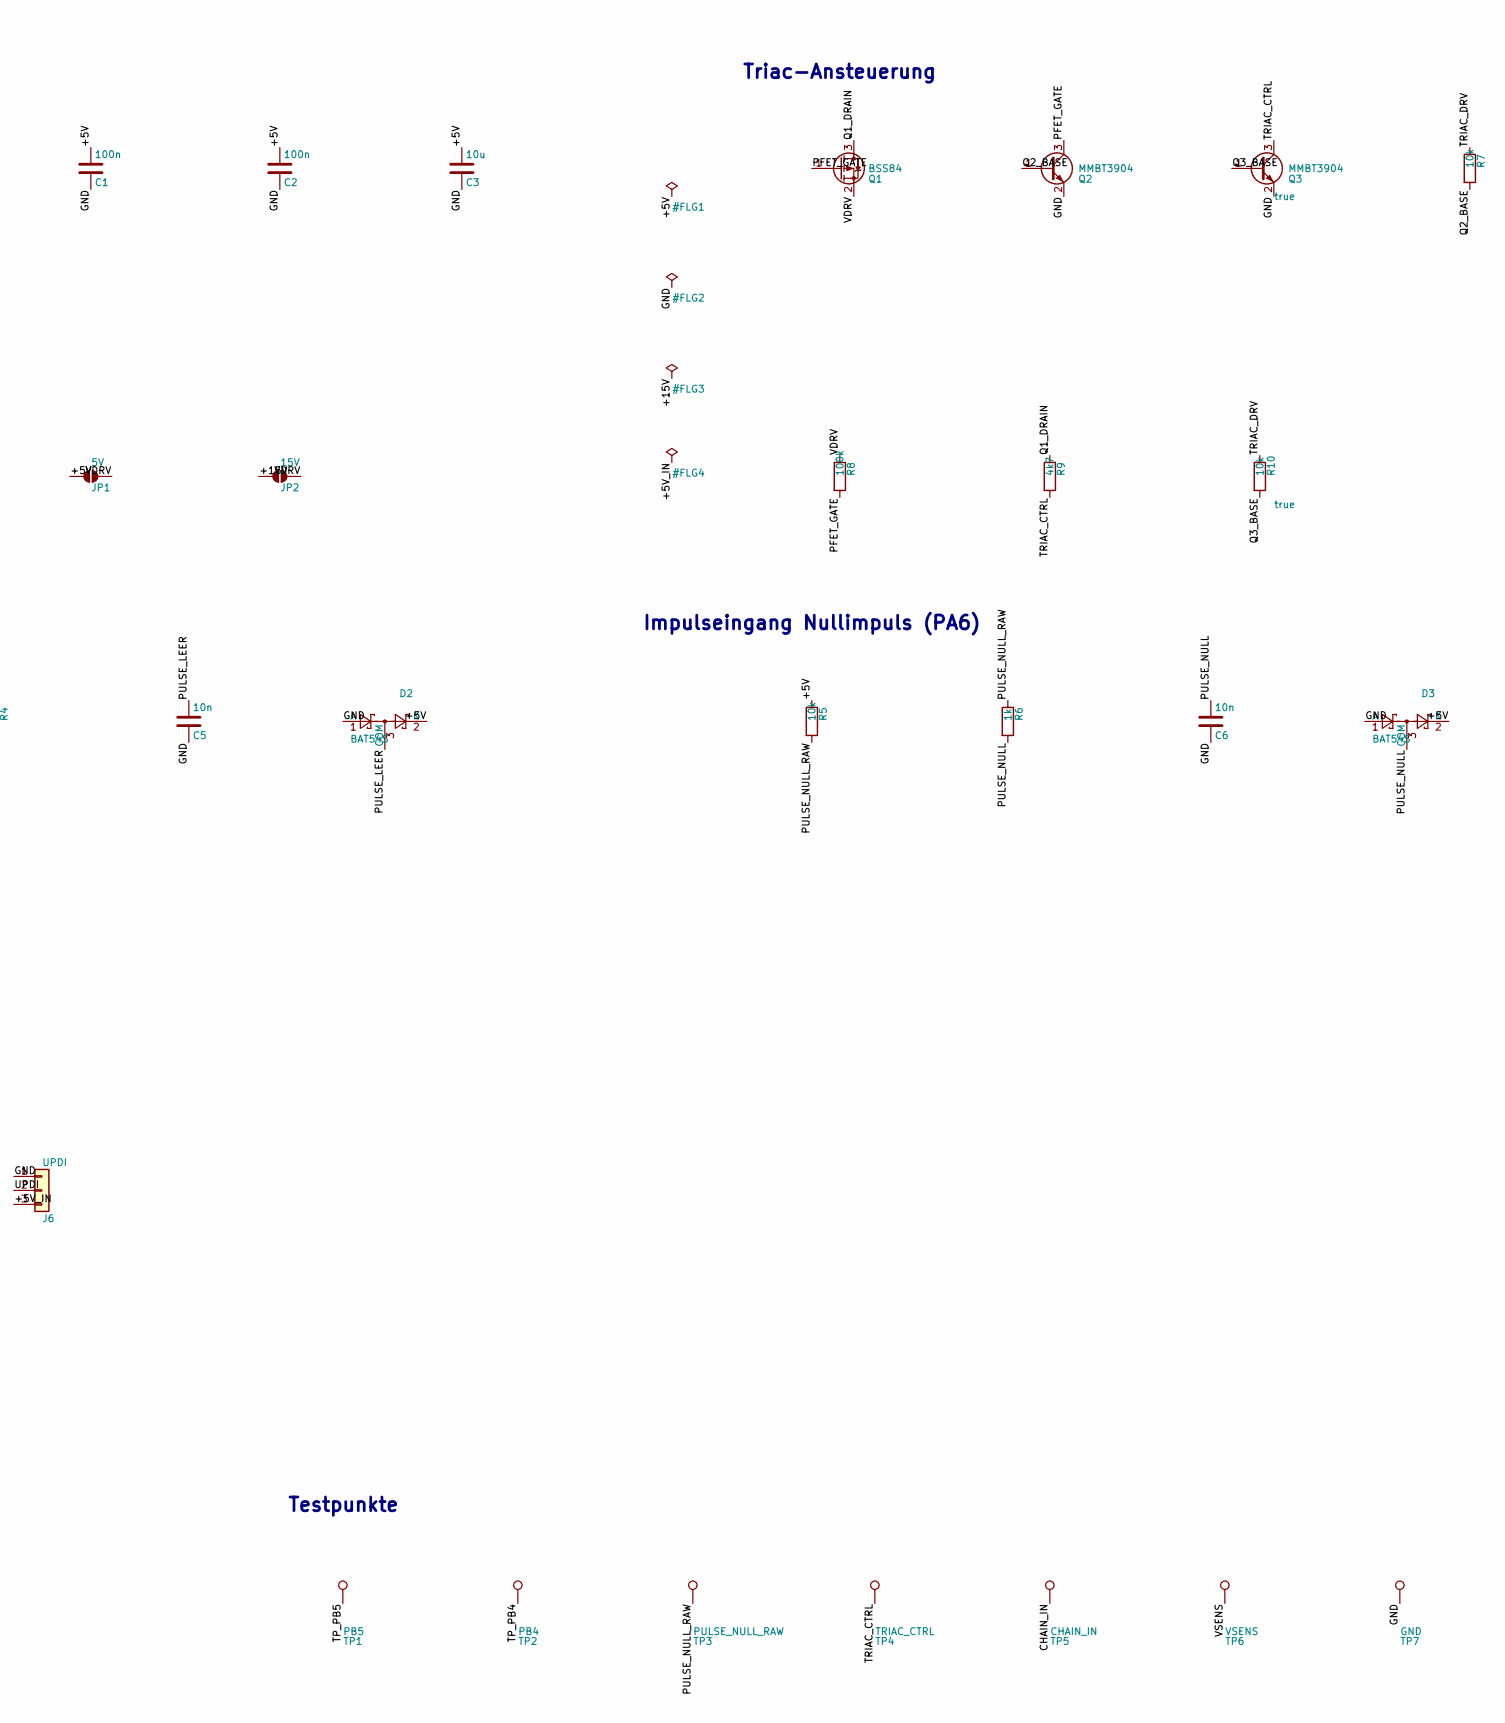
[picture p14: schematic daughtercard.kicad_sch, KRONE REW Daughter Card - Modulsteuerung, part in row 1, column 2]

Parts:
C1, C2: 100n; C_0805_2012Metric
C3: 10u; C_1206_3216Metric
C4, C5, C6: 10n; C_0805_2012Metric
D1, D2, D3: BAT54S; SOT-23
D4: gruen; LED_0805_2012Metric
F1: 0R; R_1206_3216Metric
J1: Anzeige; PinSocket_2x05_P2.54mm_Vertical
J2: Bus in; IDC-Header_2x05_P2.54mm_Vertical
J3: Bus out; IDC-Header_2x05_P2.54mm_Vertical
J4: 42V~ in; TerminalBlock_Phoenix_MKDS-1,5-2-5.08_1x02_P5.08mm_Horizont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
J5: 42V~ out; TerminalBlock_Phoenix_MKDS-1,5-2-5.08_1x02_P5.08mm_Horizont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
J6: UPDI; PinHeader_1x03_P2.54mm_Vertical
JP1: 5V; SolderJumper-2_P1.3mm_Open_Pad1.0x1.5mm
JP2: 15V; SolderJumper-2_P1.3mm_Open_Pad1.0x1.5mm
JP3: TERM; SolderJumper-2_P1.3mm_Open_Pad1.0x1.5mm
Q1: BSS84; SOT-23
Q2, Q3: MMBT3904; SOT-23
R1, R3, R5, R7, R10: 10k; R_0805_2012Metric
R2, R4, R6, R11, R13, R15: 1k; R_0805_2012Metric
R8, R12: 100k; R_0805_2012Metric
R9: 4k7; R_0805_2012Metric
R14: 0R; R_1206_3216Metric
R16: 120R; R_0805_2012Metric
TP1: PB5; TestPoint_Pad_D1.5mm
TP2: PB4; TestPoint_Pad_D1.5mm
TP3: PULSE_NULL_RAW; TestPoint_Pad_D1.5mm
TP4: TRIAC_CTRL; TestPoint_Pad_D1.5mm
TP5: CHAIN_IN; TestPoint_Pad_D1.5mm
TP6: VSENS; TestPoint_Pad_D1.5mm
TP7: GND; TestPoint_Pad_D1.5mm
U1: ATtiny1616-SNR; SOIC-20W_7.5x12.8mm_P1.27mm
U2: TP8485E-SR; SOIC-8_3.9x4.9mm_P1.27mm

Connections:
/+5V: C1.1, C2.1, C3.1, D1.2 (K), D2.2 (K), D3.2 (K), F1.2, J3.1, JP1.1 (A), R1.1, R3.1, R5.1, R14.1, U1.1 (VCC), U2.8 (VCC)
/+5V_IN: F1.1, J2.1, J6.3
/+15V: J2.9, J3.9, JP2.1 (A)
/AC1: J1.2, J4.1, J5.1
/AC2: J1.4, J4.2, J5.2
/CHAIN_IN: R11.2, R12.1, TP5.1, U1.17 (PA1)
/CHAIN_IN_RAW: J2.7, R11.1
/CHAIN_OUT: R13.1, U1.18 (PA2)
/CHAIN_OUT_EXT: J3.7, R13.2
/DE: U1.11 (PB0), U2.3 (DE)
/DI: U1.9 (PB2), U2.4 (DI)
/GND: C1.2, C2.2, C3.2, C4.2, C5.2, C6.2, D1.1 (A), D2.1 (A), D3.1 (A), D4.1 (K), J1.1, J1.3, J2.2, J2.4, J2.6, J2.8, J2.10, J3.2, J3.4, J3.6, J3.8, J3.10, J6.1, Q2.2 (E), Q3.2 (E), R12.2, TP7.1, U1.20 (GND), U2.2 (~RE), U2.5 (GND)
/LED_A: R15.1, U1.19 (PA3)
/LED_K: D4.2 (A), R15.2
/PFET_GATE: Q1.1 (G), Q2.3 (C), R8.2
/PULSE_BLATT: C4.1, D1.3 (COM), R2.2, U1.2 (PA4)
/PULSE_BLATT_RAW: J1.10, R1.2, R2.1
/PULSE_LEER: C5.1, D2.3 (COM), R4.2, U1.3 (PA5)
/PULSE_LEER_RAW: J1.8, R3.2, R4.1
/PULSE_NULL: C6.1, D3.3 (COM), R6.2, U1.4 (PA6)
/PULSE_NULL_RAW: J1.7, R5.2, R6.1, TP3.1
/Q1_DRAIN: Q1.3 (D), R9.1
/Q2_BASE: Q2.1 (B), R7.2
/Q3_BASE: Q3.1 (B), R10.2
/RO: U1.8 (PB3), U2.1 (RO)
/RS485_A: J2.3, J3.3, JP3.1 (A), U2.6 (A)
/RS485_B: J2.5, J3.5, R16.2, U2.7 (B)
/RS485_TERM: JP3.2 (B), R16.1
/TP_PB4: TP2.1, U1.7 (PB4)
/TP_PB5: TP1.1, U1.6 (PB5)
/TRIAC_CTRL: J1.9, Q3.3 (C), R9.2, TP4.1
/TRIAC_DRV: R7.1, R10.1, U1.5 (PA7)
/UPDI: J6.2, U1.16 (~RESET/PA0)
/VDRV: JP1.2 (B), JP2.2 (B), Q1.2 (S), R8.1
/VSENS: J1.5, J1.6, R14.2, TP6.1

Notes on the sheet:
MCU
RS-485-Bus
Versorgung
Triac-Ansteuerung
Impulseingang Blatt (PA4)
Impulseingang Leerbild (PA5)
Impulseingang Nullimpuls (PA6)
CHAIN / Enumeration
Status-LED / UPDI
Stecker
Testpunkte

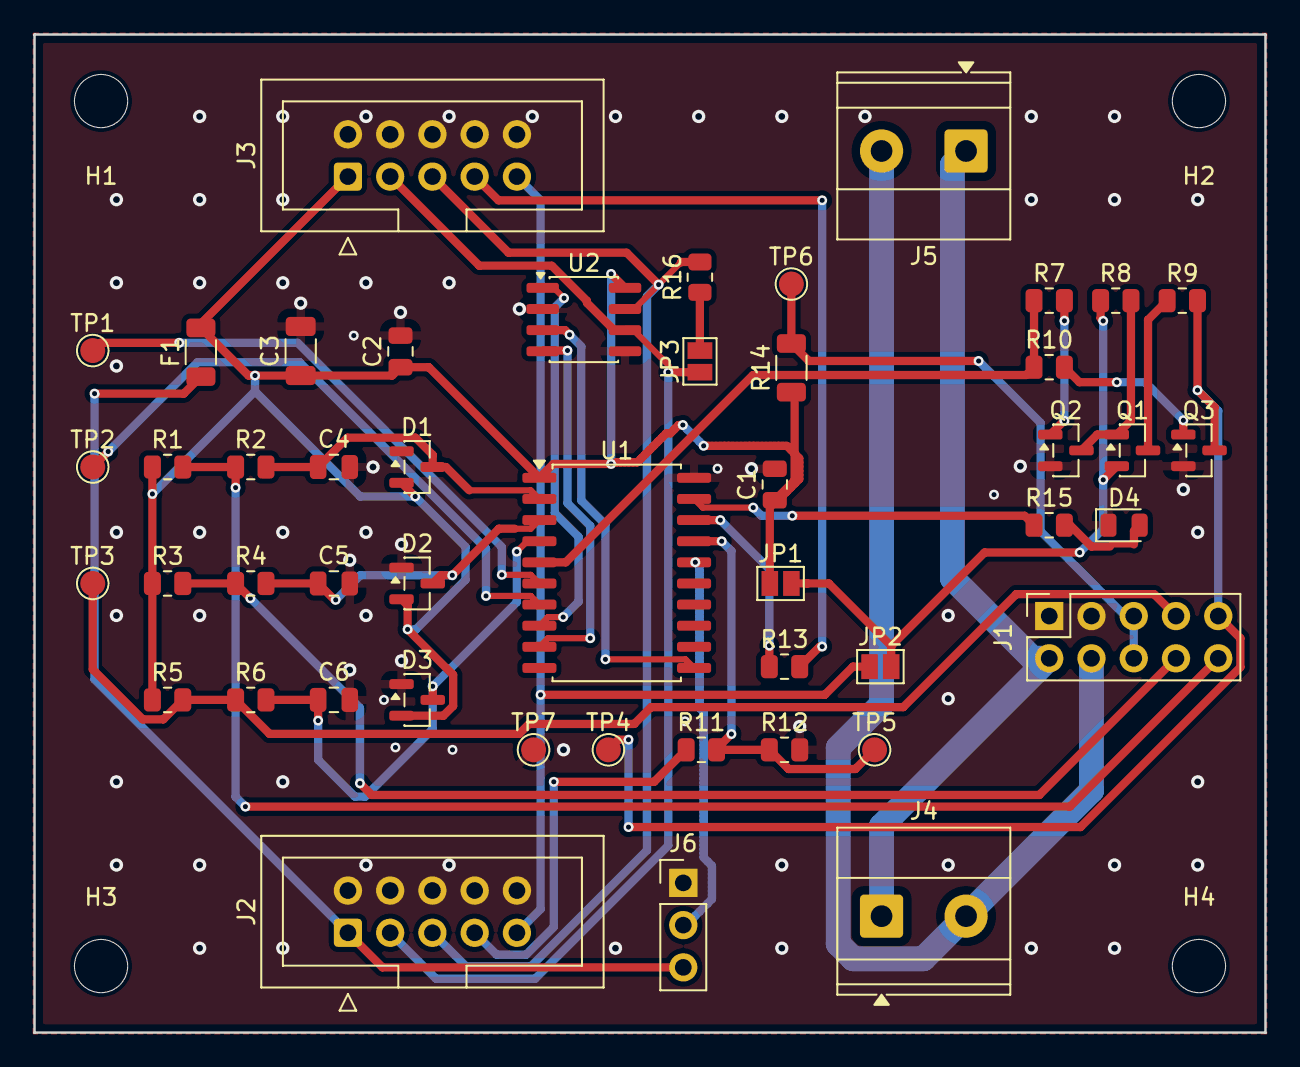
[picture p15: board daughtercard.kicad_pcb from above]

Board: 2 copper layers, 74.0 x 60.0 mm, 53 parts (1 on the bottom side), 35 nets.

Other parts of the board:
GH1: Logo_GitHub
H1, H2, H3, H4: MountingHole_3.2mm_M3

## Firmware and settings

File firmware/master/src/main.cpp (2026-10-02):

/*
 * Zentralsteuerung der KRONE-REW-Fallblattanzeige (ESP32-C3 Super Mini).
 *
 * Bindet die hardwareunabhaengigen, host-getesteten Bibliotheken an die
 * ESP32-Peripherie:
 *   lib/protocol     Rahmen/CRC (mit der Modul-Firmware geteilt)
 *   lib/busmaster    Master-Protokollseite, Enumeration, Modul-Statustabelle
 *   lib/charmap      Zeichenabbildung Text -> Fallblatt
 *   lib/clocktext    Uhrzeit -> Text
 *   lib/masterapp    Betriebsarten, Auto-Rueckfall Sekundenanzeige, Status-JSON
 *   lib/hadiscovery  Home-Assistant-MQTT-Auto-Discovery
 *   lib/eventlog     Ereignis-Ringpuffer fuer den Log-Tab der Web-UI
 *
 * Abweichungen von Spezifikation 7.2 (dependency-arm, siehe docs/toolchain.md):
 *   Web-UI/REST  -> eingebauter WebServer statt ESPAsyncWebServer
 *   Konfig       -> Preferences (NVS) statt LittleFS
 *   Captive Portal-> WiFiManager (unveraendert)
 *
 * Pin-/UART-Belegung: platformio.ini (build_flags) / docs/schaltplan-master.md.
 * Bezug: docs/spezifikation.md Kapitel 7.
 */
#include <Arduino.h>
#include <ArduinoJson.h>
#include <ESPmDNS.h>
#include <HTTPClient.h>
#include <WiFiClientSecure.h>
#include <Preferences.h>
#include <PubSubClient.h>
#include <Update.h>
#include <WebServer.h>
#include <WiFi.h>
#include <WiFiManager.h>
#include <cstdarg>
#include <memory>
#include <time.h>

#include "driver/uart.h"
#include "esp_freertos_hooks.h"
#include "esp_timer.h"
#include "lwip/apps/sntp.h"

extern "C" {
#include "busmaster.h"
#include "charmap.h"
#include "eventlog.h"
#include "hadiscovery.h"
#include "masterapp.h"
#include "moduleupdate.h"
#include "otaverify.h"
#include "protocol.h"
}
#include "module_fw.h"   /* generiert von tools/build_master_firmware.py */
#include "ota_sign.h"

/* --- Hardware --------------------------------------------------------- */
#ifndef RS485_UART_NUM
#  define RS485_UART_NUM 1
#endif
#ifndef PIN_RS485_RX
#  define PIN_RS485_RX 4
#endif
#ifndef PIN_RS485_TX
#  define PIN_RS485_TX 3
#endif
#ifndef PIN_RS485_DE
#  define PIN_RS485_DE 10
#endif
#ifndef PIN_CHAIN
#  define PIN_CHAIN 5
#endif
#ifndef PIN_STATUS_LED
#  define PIN_STATUS_LED 6
#endif

static const uart_port_t  RS485_UART   = static_cast<uart_port_t>(RS485_UART_NUM);
static constexpr int      RS485_RX_PIN = PIN_RS485_RX;
static constexpr int      RS485_TX_PIN = PIN_RS485_TX;
static constexpr int      RS485_DE_PIN = PIN_RS485_DE;
static constexpr int      CHAIN_PIN    = PIN_CHAIN;
static constexpr int      STATUS_LED   = PIN_STATUS_LED;
static constexpr uint32_t BUS_BAUD     = 115200;

/* Status-LED per Hardware-PWM (LEDC) statt Software-Bitbanging -- die
 * ESP32-loop() (WiFi/Webserver/JSON) jittert genug, dass ein per Software
 * getakteter Traeger sichtbar flackert. LEDC laeuft unabhaengig davon. */
static constexpr uint32_t LED_PWM_HZ   = 2000;
static constexpr uint8_t  LED_PWM_BITS = 8;
static constexpr uint8_t  LED_PWM_DUTY = 13;   /* ~5 % von 255 */
static constexpr uint8_t  LED_PWM_CHAN = 0;
static bool s_led_pwm_ok = false;

static const char FW_BUILD[] = __DATE__ " " __TIME__;
/* Gemeinsame Version mit der Modul-Firmware (APP_VERSION_* in
 * firmware/module/src/board.h) -- siehe firmware/CHANGELOG.md. Bei jeder
 * ausgelieferten Aenderung MINOR erhoehen und dort fortschreiben. */
static constexpr uint8_t FW_VERSION_MAJOR = 1;
static constexpr uint8_t FW_VERSION_MINOR = 16;

/* --- Zustand -------------------------------------------------------- */

static Preferences   prefs;
static WebServer     web(80);
static WiFiClient    net;
static PubSubClient  mqtt(net);

static busmaster_t   g_bus;
static masterapp_t   g_app;
static evlog_t       g_log;

struct Settings {
    char     mqtt_host[64]  = "";
    uint16_t mqtt_port      = 1883;
    char     mqtt_user[32]  = "";
    char     mqtt_pass[32]  = "";
    char     base_topic[48] = "krone/anzeige";
    char     node_id[32]    = "krone_anzeige";
    uint8_t  module_count   = 0;    /* 0 = automatisch (Enumeration), 1..32 = fester Override */
    uint32_t hms_timeout_s  = 600;

    char     ntp_server[48] = "pool.ntp.org";
    char     tz[48]         = "CET-1CEST,M3.5.0,M10.5.0/3";
    bool     ntp_enabled    = true;

    char     sep            = '.';
    uint8_t  align          = CHARMAP_ALIGN_CENTER;

    bool     use_static     = false;
    char     ip[16]   = "";
    char     mask[16] = "";
    char     gw[16]   = "";
    char     dns[16]  = "";

    bool     mqtt_enabled   = true;
    bool     api_write      = true;
    bool     ota_enabled    = true;
    bool     mdns_enabled   = true;
    bool     debug_enabled  = true;      /* Bus-Log auf der Konsole + /debug-Seite */

    /* Zugriffsschutz */
    char     admin_user[24] = "admin";
    char     admin_pass[48] = "";        /* leer = keine Anmeldung noetig */
    uint8_t  net_scope      = 1;         /* 0 alle, 1 RFC1918 (Vorgabe), 2 nur eigenes Subnetz */
} cfg;

static uint32_t last_time_ms;
static uint32_t last_autoscan_ms;
static uint32_t last_mqtt_try;
static uint32_t last_led_sync_ms;  /* nur bei Erfolg fortgeschrieben, siehe loop() */

/* --- grobe CPU-Last ueber den FreeRTOS-Idle-Hook -------------------- */
static volatile uint32_t g_idle_ticks = 0;
static uint32_t g_idle_last = 0;
static uint32_t g_idle_peak = 1;
static uint32_t g_idle_sample_ms = 0;
static uint8_t  g_cpu_load = 0;

static bool idle_hook()
{
    g_idle_ticks++;
    return true;
}

static void cpu_load_tick(uint32_t now)
{
    if (now - g_idle_sample_ms < 1000u) {
        return;
    }
    g_idle_sample_ms = now;
    const uint32_t t = g_idle_ticks;
    const uint32_t d = t - g_idle_last;   /* Wrap-around ist unkritisch */
    g_idle_last = t;
    if (d > g_idle_peak) {
        g_idle_peak = d;                  /* Selbstkalibrierung: Maximum = ~100 % frei */
    }
    g_cpu_load = (g_idle_peak > d) ? (uint8_t)(100u * (g_idle_peak - d) / g_idle_peak) : 0u;
}

/* WLAN-Wechsel mit Rueckfall auf das alte Netz */
static bool     wifi_switching = false;
static uint32_t wifi_switch_ms = 0;
static String   wifi_old_ssid, wifi_old_psk;

/* Portal-Anforderung aus der UI (im loop bearbeitet, nicht im Handler) */
static bool     want_portal = false;
static bool     want_reboot = false;
static uint32_t reboot_at = 0;


/* ================================================================== */
/* Bus-Transport                                                       */
/* ================================================================== */

/* Ringpuffer der letzten Bus-Debug-Zeilen, zusaetzlich zur seriellen
 * Konsole ueber /api/debug/buslog abrufbar (Tab "Bus-Debug" auf /debug) --
 * praktisch, wenn das Geraet gerade nicht per USB dran haengt (Issue #16). */
static constexpr uint16_t BUSLOG_LINES    = 400;   /* ~10-15 s Vorlauf bei aktueller Taktung */
static constexpr uint8_t  BUSLOG_LINE_LEN = 100;
static char     g_buslog[BUSLOG_LINES][BUSLOG_LINE_LEN];
static uint16_t g_buslog_next  = 0;
static uint32_t g_buslog_total = 0;

static void dbg_log(const char *fmt, ...)
{
    if (!cfg.debug_enabled) {
        return;
    }
    char line[BUSLOG_LINE_LEN];
    va_list ap;
    va_start(ap, fmt);
    vsnprintf(line, sizeof(line), fmt, ap);
    va_end(ap);
    Serial.println(line);
    strlcpy(g_buslog[g_buslog_next], line, sizeof(g_buslog[0]));
    g_buslog_next = (uint16_t)((g_buslog_next + 1) % BUSLOG_LINES);
    g_buslog_total++;
}

/* Diagnose fuer Issue #16 (Mehrkarten-Instabilitaet, echte Buskollision):
 * loggt jede awaiting/Retry/Timeout-Transition der busmaster-Bibliothek.
 * real_now (frisch per millis() an dieser Stelle) vs. now_ms (der von
 * loop() durchgereichte, ggf. veraltete Zeitstempel) zeigt, ob busmaster_tick()
 * mit einem Zeitstempel rechnet, der schon vor blockierenden Aufrufen
 * (web.handleClient(), mqtt.loop()) erfasst wurde. */
static void busmaster_log_cb(void *, const char *event, uint8_t cmd, uint8_t addr,
                             uint32_t now_ms, uint32_t sent_ms, uint8_t retries)
{
    const uint32_t real_now = millis();
    dbg_log("[bus] await %-7s cmd=0x%02X addr=%u now=%lu sent=%lu delta=%ld"
           " retries=%u real_now=%lu drift=%ld",
           event, cmd, addr,
           (unsigned long)now_ms, (unsigned long)sent_ms,
           (long)(now_ms - sent_ms), retries,
           (unsigned long)real_now, (long)(real_now - now_ms));
}

static void bus_tx(void *, const uint8_t *data, size_t len)
{
    if (cfg.debug_enabled) {
        char line[BUSLOG_LINE_LEN];
        int off = snprintf(line, sizeof(line), "[bus] TX %u:", (unsigned)len);
        for (size_t i = 0; i < len && off < (int)sizeof(line) - 4; ++i) {
            off += snprintf(line + off, sizeof(line) - off, " %02X", data[i]);
        }
        dbg_log("%s", line);
    }
    uart_write_bytes(RS485_UART, reinterpret_cast<const char *>(data), len);
    uart_wait_tx_done(RS485_UART, pdMS_TO_TICKS(20));
    uart_flush_input(RS485_UART);
}

static void bus_begin()
{
    uart_config_t uc = {};
    uc.baud_rate = BUS_BAUD;
    uc.data_bits = UART_DATA_8_BITS;
    uc.parity    = UART_PARITY_DISABLE;
    uc.stop_bits = UART_STOP_BITS_1;
    uc.flow_ctrl = UART_HW_FLOWCTRL_DISABLE;
    /* Grosszuegiger RX-Puffer als Marge gegen loop()-Stalls (Issue #16):
     * 2 KiB statt 512 B haelt bei 115200 Bd auch mehrere volle Antworten,
     * falls bus_pump() mal verspaetet dran kommt. */
    uart_driver_install(RS485_UART, 2048, 0, 0, nullptr, 0);
    uart_param_config(RS485_UART, &uc);
    uart_set_pin(RS485_UART, RS485_TX_PIN, RS485_RX_PIN, RS485_DE_PIN, UART_PIN_NO_CHANGE);
    uart_set_mode(RS485_UART, UART_MODE_RS485_HALF_DUPLEX);

    pinMode(CHAIN_PIN, OUTPUT);
    digitalWrite(CHAIN_PIN, LOW);
    if (STATUS_LED >= 0) {
        ledcSetup(LED_PWM_CHAN, LED_PWM_HZ, LED_PWM_BITS);
        ledcAttachPin(STATUS_LED, LED_PWM_CHAN);
        ledcWrite(LED_PWM_CHAN, 0);
        s_led_pwm_ok = true;
    }
}

/* ================================================================== */
/* Firmware-Verteilung an die Module ueber den Bus (experimentell)     */
/* ================================================================== */

static moduleupdate_t g_mu;
static proto_parser_t g_mu_parser;
static bool     g_module_fw_ok   = false;   /* eingebettete .mota gueltig     */
static const uint8_t *g_module_img = nullptr;
static uint32_t g_module_img_len  = 0;
static uint16_t g_module_img_crc  = 0;
static uint32_t g_mu_last_tick    = 0;
static uint8_t  g_mu_prev_cur     = 0;   /* fuer den ver_known-Reset nach Abschluss */

static void module_fw_verify()
{
    if (MODULE_FW_LEN < OTA_HEADER_LEN) {
        return;                                     /* ohne Signaturschluessel gebaut */
    }
    ota_header_t h;
    if (otaverify_parse_header(MODULE_FW_MOTA, MODULE_FW_LEN, 0x4000u, &h) != OTA_HDR_OK) {
        evlog_push(&g_log, 0, EVLOG_WARN, "modfw", "Container ungueltig");
        return;
    }
    if (!ota_sign_verify_header(MODULE_FW_MOTA, OTA_SIGNED_LEN, h.sig)) {
        evlog_push(&g_log, 0, EVLOG_WARN, "modfw", "Signatur ungueltig");
        return;
    }
    g_module_img     = MODULE_FW_MOTA + OTA_HEADER_LEN;
    g_module_img_len = h.img_len;
    g_module_img_crc = proto_crc16(g_module_img, g_module_img_len);
    g_module_fw_ok   = true;
    moduleupdate_init(&g_mu, bus_tx, nullptr, g_module_img, g_module_img_len,
                      g_module_img_crc, MODULE_FW_VER);
    evlog_push(&g_log, 0, EVLOG_INFO, "modfw", "Modul-Firmware v%u.%u gebundelt (%u B)",
               (unsigned)(MODULE_FW_VER >> 8), (unsigned)(MODULE_FW_VER & 0xFF),
               (unsigned)g_module_img_len);
}

/* Effektive Feldbreite: manueller Override (cfg.module_count) hat Vorrang,
 * sonst die von der Enumeration erkannte Zahl, sonst 0 (keine Module). */
static uint8_t effective_module_count()
{
    if (cfg.module_count > 0) {
        return cfg.module_count > BUSMASTER_MAX_MODULES ? BUSMASTER_MAX_MODULES
                                                        : cfg.module_count;
    }
    return g_bus.module_count;
}

static uint32_t module_online_mask()
{
    uint32_t m = 0;
    const uint8_t count = effective_module_count();
    for (uint8_t a = 1; a <= count && a <= MU_MAX_ADDR; ++a) {
        if (g_bus.mod[a - 1].online) m |= (1u << (a - 1u));
    }
    return m;
}

static void bus_pump(uint32_t now)
{
    uint8_t b;
    char rxline[BUSLOG_LINE_LEN];
    int  rxoff = 0;
    bool any_rx = false;
    if (cfg.debug_enabled) {
        rxoff = snprintf(rxline, sizeof(rxline), "[bus] RX:");
    }
    while (uart_read_bytes(RS485_UART, &b, 1, 0) == 1) {
        if (cfg.debug_enabled && rxoff < (int)sizeof(rxline) - 4) {
            any_rx = true;
            rxoff += snprintf(rxline + rxoff, sizeof(rxline) - rxoff, " %02X", b);
        }
        if (moduleupdate_busy(&g_mu)) {
            busmaster_note_activity(&g_bus, now);   /* zaehlt fuer die Busruhe */
            if (proto_parser_feed(&g_mu_parser, b) == PARSE_FRAME_OK) {
                const proto_frame_t *f = &g_mu_parser.frame;
                moduleupdate_on_frame(&g_mu, f->cmd, f->addr, f->payload, f->payload_len, now);
            }
        } else {
            busmaster_on_rx_byte(&g_bus, b, now);
        }
    }
    if (cfg.debug_enabled) {
        if (any_rx) { dbg_log("%s", rxline); }
        static bool s_chain_dbg_prev = false;
        if (g_bus.chain_active != s_chain_dbg_prev) {
            dbg_log("[bus] CHAIN -> %s", g_bus.chain_active ? "HIGH" : "low");
            s_chain_dbg_prev = g_bus.chain_active;
        }
    }
    /* CHAIN ist high-aktiv; der 74LVC1G17 hebt 3,3 V -> 5 V nicht invertierend. */
    digitalWrite(CHAIN_PIN, g_bus.chain_active ? HIGH : LOW);
}

/* Schickt ein Unicast CMD_IDENTIFY (0x40) an die Serviceadresse 250 -- die
 * Adresse, auf die eine Karte nach einer gescheiterten Enumeration
 * zurueckfaellt (Spez. 4.5.2). Damit laesst sich pruefen, ob eine Karte
 * ueberhaupt selbst sendet, unabhaengig vom Timing der Enumeration.
 * Ueber /debug erreichbar, siehe handle_debug_identify(). */
static void identify_service_test()
{
    if (cfg.debug_enabled) {
        Serial.println("[bus] === CMD_IDENTIFY an Adresse 250 (Service) ===");
    }
    /* Ueber die Sendewarteschlange, nicht direkt auf den Bus (#21). */
    busmaster_identify(&g_bus, PROTO_ADDR_SERVICE, 5);
}

/* --- Status-LED (D1 an GPIO6) ------------------------------ */

static void status_led_tick(uint32_t now)
{
    if (STATUS_LED < 0) {
        return;
    }
    const uint8_t count = effective_module_count();
    bool trouble = (WiFi.status() != WL_CONNECTED);
    for (uint8_t i = 0; i < count && !trouble; ++i) {
        if (!g_bus.mod[i].online || g_bus.mod[i].fehler != 0) {
            trouble = true;
        }
    }
    const uint32_t sync_now = now - g_bus.led_sync_ms;
    bool on;
    if (WiFi.status() != WL_CONNECTED) {
        on = (sync_now / 125) & 1;  /* 4 Hz */
    } else if (trouble) {
        on = (sync_now / 500) & 1;  /* 1 Hz */
    } else {
        on = true;
    }
    if (s_led_pwm_ok) {
        ledcWrite(LED_PWM_CHAN, on ? LED_PWM_DUTY : 0);
    } else {
        digitalWrite(STATUS_LED, on ? HIGH : LOW);
    }
}

/* ================================================================== */
/* Einstellungen (NVS)                                                 */
/* ================================================================== */
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
void loop()
{
    const uint32_t now = millis();

    /* Diagnose Issue #16: web.handleClient()/mqtt.loop() koennen gelegentlich
     * mehrere zehn/hundert ms blockieren (TCP/WiFi-Stack) -- solange busmaster
     * in dieser Zeit nicht bedient wird, laeuft sein 5-ms-Timeout faktisch
     * viel spaeter als beabsichtigt. Nur bei "Bus-Debug" aktiv, dbg_log()
     * kehrt sonst sofort zurueck. */
    const uint32_t t0 = now;
    web.handleClient();
    const uint32_t t1 = millis();
    if (t1 - t0 >= 3) { dbg_log("[loop] web.handleClient %lums", (unsigned long)(t1 - t0)); }

    handle_portal_request();
    wifi_service(millis());
    const uint32_t t2 = millis();
    if (t2 - t1 >= 3) { dbg_log("[loop] handle_portal_request %lums", (unsigned long)(t2 - t1)); }

    mqtt_ensure();
    mqtt.loop();
    const uint32_t t3 = millis();
    if (t3 - t2 >= 3) { dbg_log("[loop] mqtt %lums", (unsigned long)(t3 - t2)); }

    /* Frischer Zeitstempel fuer den Bus-Pfad -- now oben kann durch die
     * blockierenden Aufrufe schon veraltet sein (siehe drift im await-Log). */
    const uint32_t bus_now = millis();
    bus_pump(bus_now);
    if (moduleupdate_busy(&g_mu)) {
        /* Waehrend eines Modul-Updates ruht der Statusverkehr auf dem Bus. */
        if (bus_now - g_mu_last_tick >= 20) {
            g_mu_last_tick = bus_now;
            moduleupdate_tick(&g_mu, bus_now);
        }
    } else {
        busmaster_tick(&g_bus, bus_now);
    }
    /* g_bus.mod[].ver_known bleibt sonst fuer immer auf dem zuerst gelernten
     * Stand stehen (busmaster.h: "0 = unbekannt", danach nie zurueckgesetzt
     * ausser bei Enumeration) -- ohne diesen Reset zeigt die UI nach einem
     * erfolgreichen Bus-Update weiter die alte Version, weil der normale
     * Abfrageplan (busmaster_service_poll) ein bereits bekanntes Modul nie
     * erneut abfragt. Adresse wechselt in g_mu.cur, sobald eine Karte fertig
     * ist (Erfolg oder Fehlschlag) -- in beiden Faellen neu abfragen. */
    if (g_mu.cur != g_mu_prev_cur) {
        if (g_mu_prev_cur >= 1 && g_mu_prev_cur <= BUSMASTER_MAX_MODULES) {
            busmaster_invalidate_version(&g_bus, g_mu_prev_cur);
        }
        g_mu_prev_cur = g_mu.cur;
    }
    status_led_tick(now);
    cpu_load_tick(now);
    poll_events(now);

    if (want_reboot && (int32_t)(now - reboot_at) >= 0) {
        ESP.restart();
    }

    if (now - last_time_ms >= 500) {
        last_time_ms = now;
        feed_time();
    }

    /* Feldbreite der effektiven Modulzahl nachfuehren (Enumeration / Override). */
    {
        const uint8_t eff = effective_module_count();
        if (g_app.module_count != eff) {
            g_app.module_count = eff;
            g_app.have_shown = false;
            if (mqtt.connected()) {
                mqtt_publish_discovery();   /* Entity-Anzahl in HA angleichen */
            }
        }
    }

    /* Auto-Modus: solange nichts erkannt ist, alle ~10 s neu enumerieren, damit
     * spaeter angesteckte Karten von selbst auftauchen. Sobald >= 1 erkannt,
     * hoert das auf (kein Dauer-ENUM_RESET auf laufende Module). */
    static bool s_first_enum = false;
    if (!s_first_enum && now >= 3000) {
        s_first_enum = true;
        last_autoscan_ms = now;
        busmaster_start_enumeration(&g_bus, now);
    }
    if (s_first_enum && cfg.module_count == 0 && g_bus.module_count == 0 &&
        !busmaster_enum_busy(&g_bus) && !moduleupdate_busy(&g_mu) &&
        now - last_autoscan_ms >= 10000) {
        last_autoscan_ms = now;
        busmaster_start_enumeration(&g_bus, now);
    }

    /* Neue Bus-Warnungen ins Ereignislog (#28). */
    {
        static uint32_t s_warn_seq = 0;
        if (g_bus.warn_seq != s_warn_seq) {
            s_warn_seq = g_bus.warn_seq;
            const uint8_t w = busmaster_warnings(&g_bus);
            if (w & BM_WARN_UID_DUP)
                evlog_push(&g_log, now, EVLOG_WARN, "bus", "Gleiche Seriennummer auf zwei Adressen – Enumeration wiederholen");
            if (w & BM_WARN_UID_CHANGED)
                evlog_push(&g_log, now, EVLOG_WARN, "bus", "Seriennummer einer Adresse hat sich seit der letzten Enumeration geändert");
            if (w & BM_WARN_SERVICE_ADDR)
                evlog_push(&g_log, now, EVLOG_WARN, "bus", "Karte auf Serviceadresse 250 – nie enumerierte Karte am Bus");
            if (w & BM_WARN_COLLISION)
                evlog_push(&g_log, now, EVLOG_WARN, "bus", "Adresskollision (0x06) gemeldet");
            if (w & BM_WARN_ENUM_LIMIT)
                evlog_push(&g_log, now, EVLOG_WARN, "bus", "Mehr als %u Karten in der Kette", (unsigned)BUSMASTER_MAX_MODULES);
            if (w & BM_WARN_ENUM_GAP)
                evlog_push(&g_log, now, EVLOG_WARN, "bus", "Kette vorzeitig zu Ende – Karten dahinter über ihre gespeicherte Adresse erreicht");
        }
    }

    masterapp_tick(&g_app, now);

    /* Alle Karten (und der Master selbst ueber g_bus.led_sync_ms) im
     * gleichen Takt blinken lassen, statt seit dem jeweils eigenen
     * Boot-Zeitpunkt -- busmaster_led_sync() liefert false, wenn der Bus
     * gerade mit einer Antwort beschaeftigt ist (bm->awaiting); dann wird
     * es beim naechsten Tick erneut versucht, last_led_sync_ms bleibt
     * absichtlich stehen. */
    if (!moduleupdate_busy(&g_mu) && now - last_led_sync_ms >= 1000) {
        if (busmaster_led_sync(&g_bus, bus_now)) {
            last_led_sync_ms = now;
        }
    }

    /* Abfrageplan im busmaster (#20, #21): Status rundlaufend, Versionen mit
     * eigenem Zeiger, Serviceadresse; MQTT-Zustand je abgeschlossener Runde. */
    if (!moduleupdate_busy(&g_mu)) {
        if (busmaster_service_poll(&g_bus, effective_module_count(), bus_now) &&
            mqtt.connected()) {
            mqtt_publish_state();
        }
    }

    app_state_tick(now);
}

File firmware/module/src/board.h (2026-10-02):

/*
 * board.h -- die EINZIGE Datei mit hardwarenahen Konstanten der Modul-Firmware
 * (CLAUDE.md: "Alle hardwarenahen Konstanten in genau einer Headerdatei").
 *
 * Zielbaustein: ATtiny1616, SOIC-20, 20 MHz interner Oszillator.
 * Verhaltenskonstanten (Zeiten, Fehlercodes) stehen bei ihrem Automaten
 * (lib/motion, lib/enumeration), nicht hier.
 *
 * Pinbelegung nach docs/schaltplan-daughtercard.md 6.3 und docs/pruefpunkte-t7.md.
 */
#ifndef KRONE_BOARD_H
#define KRONE_BOARD_H

#include <avr/io.h>
#include <stdint.h>

#ifndef F_CPU
#define F_CPU 20000000UL
#endif

/* --- Pins ------------------------------------------------------------- */
/* Alle Signalpins liegen an PORTA. USART0 nutzt PORTB (Standard-MUX). */

#define PIN_PULSE_BLATT  PIN4_bm   /* PA4, fallende Flanke = Zaehlimpuls */
#define PIN_PULSE_LEER   PIN5_bm   /* PA5, fallende Flanke = Leerbildimpuls */
#define PIN_PULSE_NULL   PIN6_bm   /* PA6, nur Messpunkt, Firmware wertet nicht aus */
#define PIN_TRIAC        PIN7_bm   /* PA7, Ausgang zum Transistorschalter */
#define PIN_CHAIN_IN     PIN1_bm   /* PA1, Eingang (externer Pulldown R12) */
#define PIN_CHAIN_OUT    PIN2_bm   /* PA2, Ausgang, gibt die naechste Karte frei */
#define PIN_LED          PIN3_bm   /* PA3, Status-LED (aktiv high) */

#define PORT_SIGNALS     PORTA

/* USART0 Standard-MUX: TXD = PB2, RXD = PB3, XDIR = PB0. */
#define PIN_USART_XDIR   PIN0_bm
#define PIN_USART_TXD    PIN2_bm
#define PORT_USART       PORTB

/* --- Takt ----------------------------------------------------------- */
/* USART0 asynchron, Normalmodus: BAUD = (4 * F_CPU) / Baudrate. */
#define BUS_BAUD         115200UL
#define USART_BAUD_REG   ((uint16_t)((4UL * F_CPU) / BUS_BAUD))

/* 1-ms-Zeitbasis ueber TCB0 im periodischen Interruptmodus. */
#define TICK_CMP         ((uint16_t)(F_CPU / 1000UL) - 1u)

/* --- Zeitverhalten Bus (Spezifikation 5.6) ------------------------- */
#define RESPONSE_DELAY_US 200u   /* Mindest-Antwortverzug nach Rahmenende */
/* Inter-Byte-Timeout des Empfangs: ein Rahmen laeuft bei 115200 Bd ohne
 * Pause durch (87 us je Byte). Mehr als 2 ms ohne Folgebyte -> Rahmen
 * verwerfen (Vergleich in ganzen ms, wirksam nach 2..3 ms). */
#define RX_FRAME_GAP_MS   2u
/* Nach TXC hoechstens so lange auf das Echo des letzten Bytes warten
 * (~2 Zeichenzeiten); danach gehen Empfangsbytes wieder an den Parser. */
#define ECHO_TAIL_STEPS   20u
#define ECHO_TAIL_STEP_US 10u

/* --- Watchdog (Spezifikation 6.4, Zeitbasis ~1 s) ------------------ */
#define WDT_PERIOD_SETTING WDT_PERIOD_1KCLK_gc

/* --- EEPROM-Aufteilung -------------------------------------------- */
/* Byte 0..5    Konfiguration (config.h / Spezifikation 6.3)
 * Byte 8       App-gueltig-Marker des Bootloaders (firmware/bootloader)
 * Byte 16..47  Positions-Ringpuffer: 16 Paare (seq, pos), lib/posring */
#define EE_CONFIG_ADDR    0u
#define EE_POS_RING_ADDR   16u
#define EE_POS_RING_SLOTS  16u

/* --- Firmware-Version --------------------------------------------- */
/* FW_VERSION: 1 Byte, Statusbyte 7 (GET_STATUS) und PING-Antwort -- unveraendert
 * fuer Bestandscode. APP_VERSION_*: 2-Byte-Version fuer CMD_GET_VERSION und die
 * Update-Logik des Masters. Bei jeder ausgelieferten Aenderung MINOR erhoehen
 * und firmware/CHANGELOG.md fortschreiben (siehe dort). */
#define FW_VERSION        1u
#define APP_VERSION_MAJOR 1u
#define APP_VERSION_MINOR 16u

/* --- kleine Pin-Helfer ------------------------------------------- */
static inline void pin_high(PORT_t *port, uint8_t bm) { port->OUTSET = bm; }
static inline void pin_low(PORT_t *port, uint8_t bm)  { port->OUTCLR = bm; }
static inline void pin_set(PORT_t *port, uint8_t bm, uint8_t on)
{
    if (on) {
        port->OUTSET = bm;
    } else {
        port->OUTCLR = bm;
    }
}
static inline uint8_t pin_read(PORT_t *port, uint8_t bm)
{
    return (port->IN & bm) ? 1u : 0u;
}

#endif /* KRONE_BOARD_H */

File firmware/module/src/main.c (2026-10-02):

/*
 * Modul-Firmware der KRONE-REW-Fallblattanzeige (ATtiny1616, bare metal).
 *
 * Verdrahtet die getesteten hardwareunabhaengigen Automaten mit der Hardware:
 *   lib/protocol     Rahmen, CRC, Kommandotabelle          (Spez. 5)
 *   lib/enumeration  Busadress-Enumeration                 (Spez. 4.5)
 *   lib/motion       Bewegungs-Zustandsautomat             (Spez. 6)
 *   lib/config       EEPROM-Konfiguration                  (Spez. 6.3)
 *   lib/posring      Positions-Ringpuffer                  (Spez. 6.2)
 *
 * Hardwarekonstanten ausschliesslich in board.h.
 *
 * Peripherie:
 *   TCB0         periodischer Interrupt, 1-ms-Zeitbasis
 *   PORTA        fallende Flanke an PA4 (Blatt) und PA5 (Leerbild)
 *   USART0       RS-485-Modus, XDIR steuert DE byte-genau; /RE liegt fest auf
 *                GND, daher liest die Karte ihr Sendeecho zur Kollisionserkennung
 *   WDT          ~1 s, Fail-Safe fuer den Motor (Spez. 6.4); gefuettert nur,
 *                solange die 1-ms-Zeitbasis laeuft
 *   NVMCTRL      EEPROM-Schreiben ueber eine Warteschlange, nie blockierend
 */
#include <avr/eeprom.h>
#include <avr/interrupt.h>
#include <avr/io.h>
#include <avr/wdt.h>
#include <util/delay.h>

#include "board.h"
#include "config.h"
#include "enumeration.h"
#include "motion.h"
#include "posring.h"
#include "protocol.h"

/* --- Zeitbasis ------------------------------------------------------- */

static volatile uint32_t g_ms;

ISR(TCB0_INT_vect)
{
    TCB0.INTFLAGS = TCB_CAPT_bm;
    g_ms++;
}

static uint32_t millis_now(void)
{
    uint32_t v;
    cli();
    v = g_ms;
    sei();
    return v;
}

/* --- Impulseingaenge ---------------------------------------------- */

static volatile uint8_t  g_blatt_flag;
static volatile uint8_t  g_leer_flag;
static volatile uint32_t g_blatt_ts;
static volatile uint32_t g_leer_ts;

ISR(PORTA_PORT_vect)
{
    const uint8_t flags = PORTA.INTFLAGS;
    if (flags & PIN_PULSE_BLATT) {
        g_blatt_ts = g_ms;
        g_blatt_flag = 1;
    }
    if (flags & PIN_PULSE_LEER) {
        g_leer_ts = g_ms;
        g_leer_flag = 1;
    }
    PORTA.INTFLAGS = flags;
}

/* Impuls atomar abholen: Merker und 32-bit-Zeitstempel ohne ISR dazwischen
 * (#39). Rueckgabe 1, wenn ein Impuls anstand. */
static uint8_t take_pulse(volatile uint8_t *flag, volatile uint32_t *ts, uint32_t *out)
{
    uint8_t got;
    cli();
    got = *flag;
    if (got) {
        *out = *ts;
        *flag = 0;
    }
    sei();
    return got;
}

/* --- USART0: Empfang und Sendeecho ------------------------------- */

#define RX_RING_LEN 64u

static volatile uint8_t rx_ring[RX_RING_LEN];
static volatile uint8_t rx_head, rx_tail;
static volatile uint8_t rx_stamp;   /* untere 8 Bit von g_ms beim letzten Empfangsbyte */

/* Waehrend einer eigenen Sendung vergleicht die RXC-ISR die ersten
 * tx_echo_len empfangenen Bytes mit dem gesendeten Puffer, statt sie an den
 * Parser zu geben. Alles danach geht wieder in den Empfangsring. */
static volatile uint8_t        tx_echo_mode;
static volatile uint8_t        tx_echo_bad;
static volatile const uint8_t *tx_echo_buf;
static volatile uint8_t        tx_echo_len;
static volatile uint8_t        tx_echo_pos;

ISR(USART0_RXC_vect)
{
    const uint8_t status = USART0.RXDATAH;
    const uint8_t data = USART0.RXDATAL;
    (void)status;

    rx_stamp = (uint8_t)g_ms;

    if (tx_echo_mode && tx_echo_pos < tx_echo_len) {
        if (data != tx_echo_buf[tx_echo_pos]) {
            tx_echo_bad = 1;
        }
        tx_echo_pos++;
        return;
    }

    const uint8_t next = (uint8_t)((rx_head + 1u) % RX_RING_LEN);
    if (next != rx_tail) {
        rx_ring[rx_head] = data;
        rx_head = next;
    }
}

static int16_t rx_pop(void)
{
    if (rx_tail == rx_head) {
        return -1;
    }
    const uint8_t b = rx_ring[rx_tail];
    rx_tail = (uint8_t)((rx_tail + 1u) % RX_RING_LEN);
    return b;
}

/* --- Peripherie-Setup ------------------------------------------- */

/*
 * Lage der Interruptvektoren (#19).
 *
 * Boot-Variante: App ab 0x0C00 hinter dem Bootloader, Vektoren hinter der
 * BOOT-Section -> IVSEL = 0 (Reset-Standard, hier explizit).
 *
 * Plain-Variante: App ab 0x0000. Steht die Fuse BOOTEND != 0 (werksgeflashte
 * Karte, Plain-Upload schreibt keine Fuses), liegt diese App in der
 * BOOT-Section und die CPU sucht die Vektoren mit IVSEL = 0 hinter ihr, also
 * mitten im Code (Disassembly in #19: TCB0-Vektor 0x0C34 springt in main,
 * kein RETI, Interrupts tot, g_ms steht). IVSEL = 1 legt die Vektoren an den
 * Anfang der BOOT-Section = 0x0000, wo die Tabelle dieser App steht; dasselbe
 * macht megaTinyCore fuer eine ueber BOOT und APP verteilte Anwendung
 * (framework-arduino-megaavr-megatinycore, cores/megatinycore/main.cpp).
 * Register und Bit: iotn1616.h FUSE.BOOTEND (0x1288), CPUINT_IVSEL_bm (0x40);
 * CPUINT.CTRLA ist CCP-geschuetzt.
 */
static void vectors_init(void)
{
#ifdef HAS_BOOTLOADER
    _PROTECTED_WRITE(CPUINT.CTRLA, 0);
#else
    if (FUSE.BOOTEND != 0u) {
        _PROTECTED_WRITE(CPUINT.CTRLA, CPUINT_IVSEL_bm);
    }
#endif
}

static void clock_init(void)
{
    /* 20-MHz-Basis ohne Vorteiler. OSCCFG-Fuse waehlt 16/20 MHz. */
    _PROTECTED_WRITE(CLKCTRL.MCLKCTRLB, 0);
}

static void gpio_init(void)
{
    PORTA.DIRSET = PIN_TRIAC | PIN_CHAIN_OUT | PIN_LED;
    PORTA.DIRCLR = PIN_PULSE_BLATT | PIN_PULSE_LEER | PIN_PULSE_NULL | PIN_CHAIN_IN;
    PORTA.OUTCLR = PIN_TRIAC | PIN_CHAIN_OUT | PIN_LED;

    /* Fallende Flanke an Blatt- und Leerbildimpuls. Externe Pull-ups auf der
     * Karte, daher kein interner Pull-up. */
    PORTA.PIN4CTRL = PORT_ISC_FALLING_gc;
    PORTA.PIN5CTRL = PORT_ISC_FALLING_gc;

    /* XDIR und TXD muessen als Ausgang stehen, damit USART0 sie tatsaechlich
     * treibt -- sonst bleibt der Pin ein unbeschalteter Eingang, egal was die
     * Peripherie intern schiebt. */
    PORTB.DIRSET = PIN_USART_XDIR | PIN_USART_TXD;
}

static void tick_init(void)
{
    TCB0.CCMP = TICK_CMP;
    TCB0.INTCTRL = TCB_CAPT_bm;
    TCB0.CTRLB = TCB_CNTMODE_INT_gc;
    TCB0.CTRLA = TCB_ENABLE_bm;  /* CLK_PER, kein Vorteiler */
}

static void usart_init(void)
{
    USART0.BAUD = USART_BAUD_REG;
    /* RS485 External Drive: USART0 treibt XDIR waehrend der Sendung plus
     * Guard-Zeit selbst (Spez. 4.2, byte-genaue DE-Steuerung). */
    USART0.CTRLA = USART_RXCIE_bm | USART_RS485_EXT_gc;
    USART0.CTRLC = USART_CHSIZE_8BIT_gc | USART_PMODE_DISABLED_gc | USART_SBMODE_1BIT_gc;
    USART0.CTRLB = USART_RXEN_bm | USART_TXEN_bm | USART_RXMODE_NORMAL_gc;
}

static void wdt_init(void)
{
    _PROTECTED_WRITE(WDT.CTRLA, WDT_PERIOD_SETTING);
}
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

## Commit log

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2026-08-27 T2: Toolchain-Setup-Skript und Recherchestand kicad-sch-api
    tools/setup.sh richtet auf einer Debian/Ubuntu-VM KiCad 9, eine Python-venv
    mit kicad-sch-api, kicad-skip und PlatformIO ein und verifiziert alle
    Versionen. Der geforderte Nachweis, ob kicad-sch-api mit KiCad 9
    zusammenarbeitet, erfolgt als automatischer Schreib-/Lesetest; schlaegt er
    fehl, faellt das Skript auf kicad-skip zurueck.
    kicad-sch-api 0.5.6 dokumentiert weiterhin nur KiCad 7/8. Der Recherchestand
    ist in docs/toolchain.md festgehalten.
    .gitattributes erzwingt LF fuer Skripte und KiCad-Dateien (Zielumgebung Linux).
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2026-08-28 T2-Nachtrag: Toolchain auf Ubuntu 24.04 verifiziert, setup.sh-Probe korrigiert
    bash tools/setup.sh ist auf einer frischen Ubuntu-24.04-Umgebung durchgelaufen:
    KiCad 9.0.9 (PPA), kicad-sch-api 0.5.6, kicad-skip 0.2.5, PlatformIO 6.1.19.
    Der Roundtrip-Test war zunaechst falsch negativ. Ursache lag nicht bei KiCad 9,
    sondern in der Probe selbst: sie rief sch.components.add_component() bzw.
    add_symbol() auf. In kicad-sch-api 0.5.x heisst die Methode sch.components.add().
    Dadurch fiel setup.sh faelschlich auf kicad-skip zurueck und brach mit Exit 1 ab.
    - tools/setup.sh: Probe ruft jetzt .add() (mit add_component/add_symbol als
    Rueckfall) und faengt Fehler robuster ab.
    - docs/toolchain.md: Ver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
2026-08-28 T7 (P-3): RS-485 auf die USART0-Standardpins des ATtiny1616 korrigiert
    Vom Betreiber freigegeben. RO an PB3 (Pin 8, war PB1), DE an PB0 (Pin 11, war
    PB3), DI an PB2 (Pin 9) unveraendert. PB1 (Pin 10, USART0 XCK) wird neuer
    unbeschalteter Reserve-Pin.
    - tools/gen_daughtercard_sch.py: Netze RO/DE, NO_CONNECT_PINS (PB1 statt PB0).
    Schaltplan, PDF, PNG und Netzliste neu erzeugt. ERC weiter 0 Fehler / 0 Warnungen.
    - docs/schaltplan-daughtercard.md v0.3 (5.2, 6.2, 6.3, Aenderungshistorie)
    - docs/spezifikation.md v0.5 (4.2, Anhang D)
    - docs/symbolpruefung.md: NL-Spalte in 2.1 nachgezogen (Datenblattpruefung unberuehrt)
    - docs/pruefpunkte-t7.md: Freigabe eingetragen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
    [daughtercard.kicad_sch]
2026-08-28 T7: Modul-Firmware ATtiny1616 (bare metal)
    Verdrahtet die getesteten Automaten mit der Hardware. Kein Arduino-Framework:
    5303 B Flash (Grenze 8 KB), 184 B RAM, voller Zugriff auf USART0-RS485, TCB0
    und Watchdog. Toolchain.md Abschnitt 4 entsprechend angepasst.
    Neue hardwareunabhaengige Bibliotheken (host-getestet):
    - lib/motion/ Bewegungs-Zustandsautomat HOMING/IDLE/MOVING/ERROR (Spez. 6):
    Homing mit Leerbild-Sync und Blattzahlerkennung, Weg = (Ziel-Ist) mod
    Blattzahl nur vorwaerts, 20-ms-Sperrzeit, Abschaltvorhalt, Fehlercodes
    0x01-0x05, Laufzeitueberwachung.
    - lib/config/ EEPROM-Konfiguration (Spez. 6.3): Struktur, Vorgaben,
    Serialisierung, Bereichspruefung.
    src/board.h die ei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
    [board.h, main.c, test_motion.c]
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2026-08-28 Repo-Review: Sendeecho-Bug, tote Funktion, IDENTIFY
    busmaster: Bei /RE fest auf GND liest der Master sein eigenes Sendeecho zurueck.
    Ein leeres GET_STATUS-Echo bzw. das 1-Byte-ENUM_ASSIGN-Echo konnten die
    `awaiting`-Flanke vorzeitig loeschen und die echte Antwort verschlucken. Jetzt
    werden Antworten an der Payload-Laenge vom Echo unterschieden (GET_STATUS >= 8,
    ENUM_ASSIGN-ACK == 0). Zusaetzlich verwirft main.cpp das Echo mit
    uart_flush_input nach jeder Sendung. Regressionstest ergaenzt (34/34).
    firmware/module/src/main.c:
    - save_config_bytes(): leere Stub-Funktion entfernt, Kommentar an die Stelle
    des tatsaechlichen EEPROM-Schreibens verschoben.
    - CMD_IDENTIFY: blinkt die Status-LED jetz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
    [main.c, main.cpp]
2026-08-28 CI: fehlende KiCad-Bibliotheken; Generatoren robuster
    Die GitHub-Action "Schaltplan-ERC" schlug fehl, weil kicad-symbols /
    kicad-footprints / kicad-templates bei KiCad 9 nur ein Recommends sind und
    mit --no-install-recommends nicht mitkamen. Das brach tools/build_krone_symbols.py
    (--check) mangels /usr/share/kicad/symbols. Der Schaltplan selbst und ERC waren
    in Ordnung.
    - ci.yml: kicad-symbols/-footprints/-templates explizit installieren (ohne
    3D-Modelle). build_krone_symbols.py --check ist jetzt continue-on-error
    (ein KiCad-Patch-Release kann eine Neuerzeugung von krone.kicad_sym noetig
    machen, ohne dass der Build rot wird).
    - gen_daughtercard_sch.py --check-only liest die Pinlisten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
    [daughtercard.kicad_pcb]
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2026-08-31 PCB gerouted: alle Bahnen 0,5 mm ausser AC, schwarze Platine, Maker-Mark
    Routing-Lauf auf der Betreiber-Platzierung (J1-J5 fix). FreeRouting 2.3.0
    plus tools/finish_routes.py fuer die 1-2 Verbindungen, die FreeRouting
    offen laesst (Rastersuch-Router). Masseflaeche F.Cu + B.Cu mit
    Stitching-Raster und je einem Via an jedem GND-Pad.
    Netzklassen (Betreiber-Vorgabe):
    - alle Leiterbahnen 0,5 mm (an SOIC-Pins auf 0,375 mm verjuengt)
    - nur AC1/AC2 1,5 mm
    - GND ueber die Flaeche
    Konsequenz +5V-Spannungsabfall bei 10 Modulen -> docs/jlc-bestueckung.md D-5.
    Platzierung angepasst (ausserhalb J1-J5, vom Betreiber freigegeben):
    - F1 von PTC 0,5 A auf 0-Ohm-Bruecke (R_1206 / 0R / C17888, D-3):
    F1 lieg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
    [daughtercard.kicad_pcb, daughtercard.kicad_sch]
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2026-09-01 LCSC-Nummern gegen JLC-API geprueft: alle Positionen zugeordnet
    Beim JLC-Upload aufgetreten und behoben:
    - D4 (gruene LED) ohne LCSC-Nummer -> JLC-Auto-Match auf eine 0201-LED
    -> Zwang zu Standard PCBA (25 USD/Seite, Platine auf 74x70 mm). Fest
    auf C2297 gesetzt (KT-0805G, 0805, Basic). Economic PCBA bleibt, das
    Platinenmass bleibt 74x60 mm.
    - R8, R12 (100k 0805): C17407 von JLC stillgelegt (Bestand 0) -> C149504
    (Basic, Lager > 5 M).
    - Q1 (BSS84): C8492 (LBSS84LT1G, LRC, SOT-23, Lager > 260 k) statt
    Auto-Match mit 7 Stueck. Extended, aber Economic-tauglich.
    - D1-D3 (BAT54S): C19726 (BAT54SLT1G onsemi, SOT-23, Lager > 500 k)
    statt "im Cart waehlen".
    Damit hat jede BOM-Position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
    [BOM.csv]
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2026-09-01 Master: Schaltplan + geroutete PCB + Fertigungspaket (T11)
    hardware/master/ -- ESP32-C3 Super Mini Traegerboard, 68x54 mm, 2 Lagen:
    - master.kicad_sch aus schaltplan-master.md Kap. 6, ERC 0/0. 29 Bauteile,
    19 Netze. TP8485E @ 3,3 V, Fail-Safe-Bias + fester 120-Ohm-Abschluss,
    CHAIN-Pegelwandler 74LVC1G17 (M-3), Ader-9-Loetbruecke + Boost-Steckplatz
    DNP (M-2/O-2), 5-V-Eingang. Keine 42 V~ auf der Platine.
    - master.kicad_pcb: FreeRouting 2.3.0 + finish_routes + Masseflaechen
    F.Cu/B.Cu + Stitching. DRC 0 Fehler / 0 unverdrahtet (3 kosmetische
    Silk-Warnungen). Schwarz/weiss, GitHub-Marke + "TenOfNine" auf B.SilkS.
    - manufacturing/: Gerber + Zip + BOM (12 Positionen, alle mit gepruefter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
    [BOM.csv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]
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2026-09-01 Master-Web-UI: Dark-Theme, Log, erweiterte Einstellungen
    Neue Weboberflaeche (eine PROGMEM-Seite, System-Fonts, kein CDN, ~14 KB):
    Sidebar-Navigation, Ansichten Uebersicht (Split-Flap-Statusstreifen,
    Kacheln, Schnellaktionen), Module (Tabelle), Log, Einstellungen.
    REST erweitert:
    GET /api/system Uptime/Heap/WLAN/Uhr/MQTT/OTA/mDNS/Bus-CRC+Timeouts/FW
    GET /api/log Ereignis-Ringpuffer (?sev=info|warn|err)
    POST /api/log/clear, /api/module, /api/enumerate, /api/time,
    /api/wifi (Netzwechsel + Rueckfall), /api/wifi/scan,
    /api/wifi/portal, /api/reboot
    /api/config: NTP-Server, Zeitzone, feste IP (DHCP/statisch),
    Ausrichtung, Trennzeichen, sowie Schalter MQTT / R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
    [main.cpp]
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2026-09-09 Fix: ATtiny1616-Signatur 1E 94 21 (war 1E 94 22); README-Ausblick konkreter
    Die Geräte-ID-Prüfung im Browser-UPDI-Flasher stand auf 1E 94 22 -- das ist
    der ATtiny1614. Laut pymcuprog (Microchip DFP 2.4.111) und avrdude.conf ist
    ATtiny1616 = 1E 94 21. Mit dem falschen Wert hätte updi.js jeden echten
    ATtiny1616 abgewiesen. Korrigiert in updi.js, build_module_firmware.py
    (Docstring + README-Vorlage), firmware/module/prebuilt/README.md,
    spezifikation.md (Changelog v0.17), backlog.md T16.
    README "Ausblick": der Bootloader-Weg (Firmware über den Bus verteilen) jetzt
    als konkreterer Ansatz ausformuliert -- residenter Bootloader im BOOTEND-Bereich,
    Update-Frames über die vorhandene RS-485-Rahm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
    [build_module_firmware.py]
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2026-09-09 Modul-Bootloader + env attiny1616_boot (experimentell)
    firmware/bootloader/ -- residenter Bootloader (~2,5 KiB, Boot-Sektion 3 KiB,
    Fuse BOOTEND = 0x0C, App ab 0x0C00). Reset -> Bootloader: prueft Marker
    (GPIOR0 == 0xB7) und App-Gueltigkeit, startet sonst die App bzw. empfaengt
    eine neue ueber USART0/RS-485 (lib/protocol + lib/fwupdate) und schreibt sie
    per NVMCTRL (Erase+Write). Kein Interrupt, eigener Watchdog. PA7 (Triac) wird
    nie als Ausgang konfiguriert -> der Motor kann im Bootloader nicht bestromt
    werden. Nutzt CPUINT.CTRLA.IVSEL fuer die Vektortabelle (keine Trampoline).
    firmware/module:
    - env attiny1616_boot: wie attiny1616, aber .text @ 0x0C00 + -DHAS_BOOTLOADER.
    env:attiny1616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
    [board.h, main.c]
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2026-09-09 Fix: Web-UI komplett tot -- Anfuehrungszeichen sprengte den Inline-Script
    In renderMods stand im Leerzustand-String der Modul-Tabelle ein ASCII-"
    mitten im JS-String-Literal ("... „Enumeration neu starten"."). Das schloss
    den String vorzeitig -> SyntaxError im gesamten <script> -> keine
    Event-Handler wurden verdrahtet, nichts war mehr klickbar (seit PR #12).
    - Text umformuliert, kein ASCII-Anfuehrungszeichen mehr im String.
    - tools/check_webui.mjs (neu): prueft die Syntax jedes Inline-<script> in
    INDEX_HTML (vm.Script, ohne Abhaengigkeit) und macht optional einen
    jsdom-Smoke-Test (Seite laden, /api/* mocken, Navigationsklick). Faengt
    genau diese Fehlerklasse.
    - CI (host-tests): 'nod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
    [main.cpp]
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2026-09-10 build_webui_demo: Pages-Job brach am kosmetischen relative_to() ab
    Mit -o _site/demo/index.html (Ziel ausserhalb des Repos) warf
    args.out.relative_to(REPO) einen ValueError -- die Demo war da schon
    geschrieben, nur die Erfolgsmeldung crashte und der Pages-Job lief auf
    exit 1. Pfad jetzt vor der Ausgabe aufloesen, sonst unveraendert anzeigen.
    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
    [build_webui_demo.py]
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2026-09-11 Doku: Browser-UPDI-Werksflasher der Daughter Card als verifiziert markiert
    Am 10.09.2026 vom Betreiber getestet: Chip-Erase, Geraete-ID-Pruefung,
    Fuse- und Seitenschreiben (BOOTEND = 0x0C) sowie die Bootloader->App-
    Uebergabe (IVSEL/Vektortabelle) liefen auf echter Hardware durch. Der
    vorherige Fehlschlag ("Timeout: 1/66 B") war der fehlende CTRLA.RSD-Block-
    schreibmodus in updi.js, bereits mit 59710f8 behoben.
    Aktualisiert: README.md, docs/module-bootloader.md (Status-Banner +
    Bench-Checkliste Punkte 1+2), docs/spezifikation.md (Kap. 5.7, v0.22),
    docs/backlog.md (T16), docs/projektstand.md, firmware/master/prebuilt/
    index.html (Flasher-Banner). Die Firmware-Verteilung ueber den Bus selbst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
2026-09-12 busctl.py: Vorlaufzeit vor dem Senden ergaenzt (RS485_TX_SETTLE_S)
    Bisher gab es nur eine Nachlaufzeit nach dem letzten Byte, bevor DE/RTS
    zurueck auf Empfang faellt. RTS/DTR setzen ist ein USB-Control-Transfer und
    wirkt nicht synchron zur Byte-Uebertragung -- ohne Vorlauf kann das die
    ersten Bytes eines Frames (bei uns die Praeambel) kappen, symmetrisch zum
    bereits behobenen Nachlauf-Fall (CRC). delay_before_tx bei --rts-rs485
    ergaenzt, manueller Sleep vor dem Schreiben bei --dtr-rs485.
    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
    [busctl.py]
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2026-09-12 Fix: README-Logo wurde nicht gerendert (kaputtes img-Tag)
    Der alt-Text enthielt "„K"" -- die eingebettete Anfuehrungszeichen-
    Kombination hat das Attribut vorzeitig geschlossen, GitHub hat das
    Tag deshalb als Text statt als Bild dargestellt. alt-Text vereinfacht.
    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
2026-09-19 Fix: TXD-Pin (DI) der Modul-USART0 wurde nie als Ausgang konfiguriert
    gpio_init() setzte in PORTB.DIRSET nur XDIR (PB0), nicht TXD (PB2). Ohne
    gesetztes DIR-Bit kann USART0 den DI-Pin zu U2 nicht treiben, obwohl DE
    korrekt schaltet und die Peripherie intern gueltige Bytes schiebt -- die
    Karte "versucht" zu antworten, aber am Bus kommt nur ein eingefrorener
    Pegel an. Erklaert die durchgaengig gescheiterte Enumeration auf allen
    Daughter Cards (nicht plattenspezifisch), gefunden per Logic-Analyzer-
    Mitschnitt an A/B/DE/DI waehrend eines echten ENUM_ASSIGN-Zyklus.
    Fix: PIN_USART_TXD (PIN2_bm) ergaenzt, PORTB.DIRSET setzt jetzt beide Pins.
    Prebuilt-Firmware (Hex/.mota) mit tools/build_module_fir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
    [board.h, main.c]
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2026-09-19 Fix: Firmware-Versionsabfrage der Module wurde bei <4 Modulen nie ausgeloest
    busmaster_poll_version() haengt an "poll_addr % 4 == 0", aber poll_addr
    zykelt ueber (poll_addr % count) + 1 -- bei count<4 (z.B. genau 1 Modul,
    poll_addr bleibt konstant 1) ist dieser Ausdruck nie 0. Die Versions-
    abfrage kam dadurch nie zum Zug, das Modul blieb dauerhaft auf
    "VERSION UNBEKANNT" / "kein BL" stehen (Letzteres ein Nebeneffekt des nie
    gefuellten ver_flags-Feldes, nicht ein echter Bootloader-Befund).
    Neuer, von poll_addr/count unabhaengiger Zaehler poll_cycle fuer das
    1-von-4-Gating.
    Claude-Session: https://claude.ai/code/session_01UsXTvE3jGgoK5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
    [main.cpp]
2026-09-19 Prebuilt-Master-Firmware neu erzeugt (war seit 01dcdd0 nicht mehr gebaut)
    factory.bin + signiertes .kota fuer USB-Erstflash und Browser-OTA lagen
    noch auf dem Stand vor der gesamten heutigen Fehlersuche und den LED-/
    Debug-Einstellungen-Aenderungen. Enthaelt jetzt ausserdem das aktuelle
    eingebettete Modul-Firmware-Image (module_fw.h) mit dem DI-Pin-Fix, das
    der Master fuer die experimentelle Firmware-Verteilung ueber den Bus
    mitbringt.
    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
2026-09-19 LED: Master auf Hardware-PWM (LEDC), beide LEDs auf 10% Helligkeit
    Ursache des gemeldeten Flackerns auf dem Master: Der bisherige Software-
    PWM-Traeger lief in loop() und geriet durch WiFi/Webserver/JSON-Arbeit
    dazwischen ins Jittern -- sichtbar als unregelmaessiges Flackern statt
    gleichmaessigem Dimmen. Jetzt echte Hardware-PWM ueber ledcSetup/
    ledcAttachPin/ledcWrite (2 kHz, 8 Bit), komplett unabhaengig vom
    Loop-Timing.
    Modul (ATtiny1616) bleibt beim Software-Traeger (dort keine Rueckmeldung
    von Flackern, die bare-metal-Schleife laeuft eng genug) -- nur Deckel von
    25% auf 10% reduziert (PWM_PERIOD_MS=10, PWM_ON_MS=1).
    Master- und Modul-Prebuilt-Firmware neu erzeugt.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
    [main.c, main.cpp]
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2026-09-19 Debug-Log fuer busmaster-Zustandsuebergaenge (Issue #16)
    Optionaler Log-Hook in busmaster (busmaster_set_log): meldet jede
    send/match/retry/give_up-Transition mit cmd, addr, dem uebergebenen
    now_ms, sent_ms, der daraus berechneten Zeitdifferenz und -- als
    direkter Test der Verdachtshypothese -- einem frisch an der Log-Stelle
    selbst erfassten real_now (millis()). Wenn now_ms (aus loop() durch-
    gereicht) und real_now deutlich auseinanderlaufen, bestaetigt das, dass
    busmaster_tick() mit einem vor blockierenden Aufrufen (web.handleClient(),
    mqtt.loop()) erfassten, bereits veralteten Zeitstempel rechnet -- das
    wuerde erklaeren, warum eine Wiederholung schon nach 1,36 ms statt der
    konfigurierten 5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
    [main.cpp]
2026-09-19 Bus-Log auch in der Web-UI sichtbar (/debug)
    Kleiner Ringpuffer (40 Zeilen) faengt alle Bus-Debug-Ausgaben (TX/RX,
    CHAIN-Wechsel, Enumeration, die neuen await-Transitionen) zusaetzlich zur
    seriellen Konsole ab. Neuer Endpunkt GET /api/debug/buslog (text/plain,
    hinter cfg.debug_enabled + guard()) liefert die letzten Zeilen; /debug
    zeigt sie in einer <pre>-Liste mit 1-s-Auto-Refresh. Praktisch, wenn das
    Geraet fuer einen Logic-Analyzer-Mitschnitt gerade nicht per USB dran
    haengt (Issue #16).
    Alle bisherigen Serial.print(f)-Aufrufe im Bus-Pfad durch einen
    gemeinsamen dbg_log()-Helfer ersetzt, der sowohl auf die Konsole schreibt
    als auch den Ringpuffer fuellt -- ohne "Bus-Debug" kein zusaetzlic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
    [main.cpp]
2026-09-19 Bus-Log-Ringpuffer auf 400 Zeilen vergroessert, Auto-Refresh auf 3 s
    Erster Live-Blick auf /debug (Issue #16) zeigte: der Retry/Timeout-
    Mechanismus selbst arbeitet korrekt (delta=5ms exakt, kein Drift) --
    Adresse 2 war zum Messzeitpunkt schon dauerhaft unadressiert (Folge
    einer frueheren Kollision), nicht live beim Kollidieren erwischt. Mit
    40 Zeilen (~1 s Vorlauf bei aktueller Taktung) ist das Fenster viel zu
    kurz, um den eigentlichen Ausfallmoment im Nachhinein zu sehen. Jetzt
    400 Zeilen (~10-15 s), RAM-Kosten (~40 KB) angesichts 29% Auslastung
    unkritisch. Auto-Refresh von 1 s auf 3 s reduziert, damit das Abrufen
    der (jetzt zehnmal groesseren) Log-Seite selbst nicht zusaetzliche
    Webserver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
    [main.cpp]
2026-09-19 loop(): Blockier-Zeit von web.handleClient()/mqtt messen, frischer Zeitstempel fuer den Bus-Pfad
    Erster Live-Log (Issue #16) zeigte zwei Dinge:
    1. Bei einer Antwort fehlten genau die ersten 5 von 15 Bytes (Rest
    korrekt) -- passt zu uart_flush_input() in bus_tx(), das nach dem
    Senden aufgerufen wird und frueh eintreffende echte Antwortbytes
    mit verwerfen kann, wenn die Karte schnell genug antwortet.
    2. Viel schwerwiegender: ein await-Log-Eintrag zeigte drift=118 --
    118 ms zwischen dem in loop() erfassten Zeitstempel und der
    tatsaechlichen Uhrzeit an der Log-Stelle. Das bedeutet, loop() ist
    irgendwo (vermutlich web.handleClient() oder mqtt.loop()) fuer
    ~118 ms haengengeb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
    [main.cpp]
2026-09-19 WLAN-Modem-Sleep deaktiviert + groesserer UART-RX-Puffer (Issue #16)
    WiFi.setSleep(false) nach WiFi.mode(WIFI_STA): der ESP32-C3 schlaeft im
    Stationsmodus per Default zwischen den AP-Beacons (Modem-Sleep,
    DTIM-abhaengig ~100-300 ms) -- passt exakt zu den in Issue #16
    gemessenen 100-120-ms-Blockaden von web.handleClient(). Der Master
    haengt fest an 5 V, Stromsparen bringt hier nur Latenz ohne Nutzen.
    uart_driver_install()-RX-Puffer von 512 B auf 2 KiB angehoben, als
    zusaetzliche Marge falls bus_pump() trotzdem mal verspaetet drankommt.
    Beides zusaetzlich zum bus_now-Fix aus 3374dc0 (der bleibt als zweite
    Verteidigungslinie bestehen). Prebuilt-Firmware neu erzeugt.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
    [main.cpp]
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2026-09-19 Fix: Bootloader hatte denselben DI-Pin-Bug wie die App vor f24b861
    firmware/bootloader/src/main.c hat eine eigene, unabhaengige USART0-
    Initialisierung -- setzte dort ebenfalls nur XDIR (PB0) als Ausgang,
    nie TXD (PB2). Der Bootloader konnte CMD_FW_BEGIN/DATA/END zwar
    empfangen (RX funktioniert unabhaengig davon), aber nie ACKen. Der
    allererste reale Test der Firmware-Verteilung ueber den Bus (Master-PCB
    war bisher nicht aufgebaut, siehe docs/module-bootloader.md) deckte das
    sofort auf: FW_BEGIN markiert die App bereits als ungueltig, bevor die
    fehlende ACK-Antwort den Master zum Abbruch zwingt -- beide Karten
    blieben danach im (jetzt reparierten) Bootloader haengen, dunkel und
    ueber den Bus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
    [board.h, main.c, main.cpp]
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2026-09-19 Fix: Marke verschwand beim horizontalen Scrollen der Mobil-Navigation
    .side wurde unter 820px Breite als ein einziger horizontal scrollender
    Block gerendert (.brand + .nav zusammen) -- Scrollen zur Einstellungen-
    Kachel schob die Marke "KRONE REW / Zentralsteuerung" mit aus dem
    Bildschirm. Marke bekommt jetzt flex:none und bleibt fest stehen, nur
    die Tab-Leiste scrollt in ihrem eigenen Container.
    Firmware v1.11 (Master + Modul gemeinsam, siehe firmware/CHANGELOG.md).
    [board.h, main.cpp]
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2026-09-21 Fix: Modul-Version in der UI blieb nach erfolgreichem Bus-Update stehen
    g_bus.mod[].ver_known wurde nach der ersten erfolgreichen
    CMD_GET_VERSION-Antwort nie zurueckgesetzt (busmaster_start_enumeration
    ist der einzige bestehende Reset). Der reguelaere Versions-Poll in
    loop() waehlt aber nur Module mit !ver_known aus ("einmalig abfragen"),
    fragt ein einmal gelerntes Modul also nie wieder ab -- auch nicht nach
    einem Bus-Firmware-Update, das die tatsaechliche Version aendert.
    lib/moduleupdate bestaetigt die neue Version zwar korrekt intern
    (MU_P_CONFIRM), schreibt das aber nicht in g_bus.mod[] zurueck, daher
    zeigte /api/module/firmware weiterhin die alte Version, obwohl das
    Update laut Meldung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
    [board.h, main.cpp]
2026-09-21 Feature: Status-LEDs blinken master-synchron statt phasenversetzt
    Bisher lief jede Karte (und der Master) das Blink-Muster (4 Hz
    Identify, 1 Hz Fehler) relativ zum eigenen Boot-Zeitpunkt -- ohne
    gemeinsamen Bezugspunkt driftet die Phase zwischen den Karten
    beliebig auseinander.
    Neuer Broadcast CMD_LED_SYNC (0x41, kein Payload, keine Antwort,
    lib/protocol) fuellt diese Luecke: der Master sendet ihn alle ~1 s
    (busmaster_led_sync(), faellt in einen laufenden Antwort-Wechsel
    nicht ein), Module und Master selbst nullen darauf ihren jeweiligen
    now-Bezugspunkt (g_led_sync_ms) fuer die Blinkphase-Berechnung.
    Der PWM-Helligkeits-Traeger (~50 Hz, 5 % Deckel) bleibt unangetastet,
    da rein kosmetisch un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
    [board.h, main.c, main.cpp]
2026-09-21 Fix: Karte im Bootloader nach abgebrochenem Update nie wieder erreichbar
    Bricht die Firmware-Verteilung ueber den Bus mitten in FW_DATA/FW_END
    ab, bleibt die App auf der Karte absichtlich als ungueltig markiert
    (dokumentierter Fail-Safe, docs/module-bootloader.md) -- der Bootloader
    wartet dann unbegrenzt auf ein neues FW_BEGIN. Der Bootloader
    implementiert aber kein CMD_GET_STATUS, also gilt die Karte dem
    Master ab da als offline (mod[].online=false).
    handle_module_update() filtert "Alle aktualisieren" wie auch
    "Veraltete aktualisieren" auf online -- eine so haengen gebliebene
    Karte konnte der Master damit nie wieder ansprechen, geschweige denn
    den Update-Versuch wiederholen, der sie zuruec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
    [board.h, main.cpp]
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2026-09-25 Fix: Moduswahl "Text" sprang vor dem Absenden zurueck
    Klick auf "Text" schaltet den Button lokal um und blendet die
    Eingabe ein, sendet aber bewusst noch keinen /api/mode-Aufruf --
    erst "Senden" (POST /api/text) schaltet den Server tatsaechlich auf
    Textmodus (masterapp_set_text() setzt app->mode). Der Status-Poll
    alle 2,5 s glich die Anzeige aber sofort mit dem unveraenderten
    Server-Modus ab und schnappte damit zurueck, bevor ueberhaupt etwas
    eingetippt werden konnte.
    Neues textPending-Flag: wird beim Klick auf "Text" gesetzt, beim
    Senden oder beim Wechsel auf einen anderen Modus-Button wieder
    geloescht, und unterdrueckt den Abgleich, solange es aktiv ist.
    Firmware v1.15 (Master + Modul ge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
    [board.h, main.cpp]
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2026-10-02 Modul: Sicherheits- und Bus-Fixes aus dem Review (Bit 2, IVSEL, Positionsring, Zielpuffer)
    - Flag-Bit 2 (Triac-Polaritaet) entfaellt: Gate = motor_on in allen
    Zustaenden, ungueltige/geloeschte EEPROM-Abbilder werden auf die Vorgaben
    migriert (gueltige Busadresse bleibt), Vorhalt > 60 -> 0 (#18).
    - Plain-App setzt bei BOOTEND != 0 IVSEL=1; Watchdog nur bei laufender
    Zeitbasis; nach WDT-Reset Start in ERROR 0x05 mit Motor aus (#19).
    - SET_CONFIG wirkt sofort (motion_apply_config), ACK vor dem EEPROM (#23).
    - Positionsspeicher als host-testbare lib/posring: seq ohne 0xFF, pos vor
    seq, Ungueltig-Eintrag bei Fahrtbeginn, nur ohne Autohoming (#24).
    - EEPROM-Schreiben ueber nicht blockieren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
    [board.h, main.c, test_motion.c]
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
